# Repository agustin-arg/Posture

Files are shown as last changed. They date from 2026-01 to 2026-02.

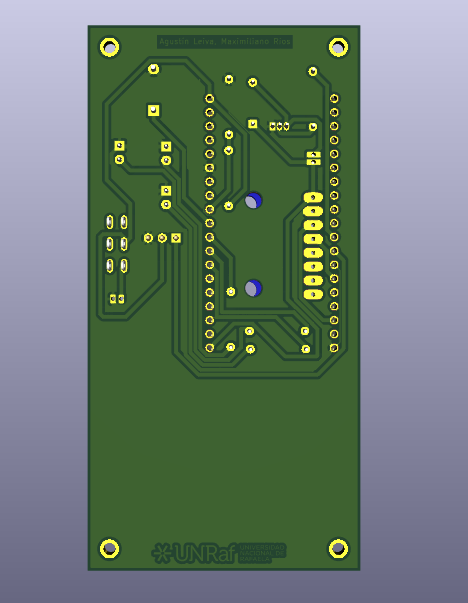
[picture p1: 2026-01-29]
pcb/design/renders/Vista inferior de la PCB - distribución de pistas y puntos de soldadura..png

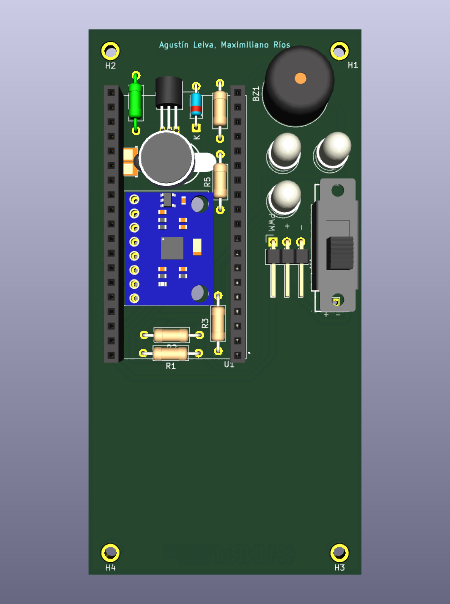
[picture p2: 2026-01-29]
pcb/design/renders/Disposición de componentes en la placa base (sin módulo de control).png

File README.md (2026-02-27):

# **Posture**

Un dispositivo *wearable* que detecta malas posturas en tiempo real y ofrece retroalimentación háptica (vibración), acción mecánica (servomotor), visual (LEDs) y auditiva (buzzer). Incluye conectividad **Bluetooth Low Energy (BLE)** para configuración y monitoreo remoto.

## **Características**

* **Feedback Multimodal:**  
  * **LED Rojo:** Mala postura.  
  * **LED Verde:** Postura correcta.  
  * **Buzzer:** Alerta sonora.  
  * **Vibrador:** Alerta táctil.  
  * **Servomotor:** Acción mecánica correctiva (opcional).  
* **Conectividad BLE:** Permite ver el estado, calibrar y configurar umbrales desde la App móvil.  

## **🛠️ Hardware Requerido y Conexiones**

| Componente | Pin ESP32 (GPIO) | Descripción |
| :---- | :---- | :---- |
| **MPU6050 SDA** | GPIO 21 | Datos I2C |
| **MPU6050 SCL** | GPIO 22 | Reloj I2C |
| **LED Rojo** | GPIO 25 | Indicador de mala postura |
| **LED Verde** | GPIO 33 | Indicador de postura correcta |
| **LED Azul** | GPIO 32 | Estado Bluetooth / Calibración |
| **Buzzer** | GPIO 26 | Alarma sonora (PWM) |
| **Vibrador** | GPIO 18 | Motor de vibración |
| **Servomotor** | GPIO 19 | Servo para corrección física |

## **📂 Estructura del Proyecto**

El código está organizado en 6 archivos para facilitar el mantenimiento:

1. main.py: **Punto de entrada**. Orquesta la inicialización y el bucle principal.  
2. config.py: **Configuración**. Almacena pines, constantes y UUIDs de Bluetooth.  
3. mpu6050.py: **Driver**. Manejo de bajo nivel del sensor I2C.  
4. actuators.py: **Hardware**. Controla LEDs, buzzer, motor y servo.
5. ble\_service.py: **Comunicaciones**. Gestiona la publicidad BLE, conexión y características GATT.  
6. posture\_logic.py: **Matemáticas**. Contiene la física pura y el filtro complementario para calcular el ángulo.

## **🚀 Instalación y Uso**

1. **Flashear MicroPython:** Asegúrate de que tu ESP32 tenga instalado el firmware de MicroPython más reciente.  
2. **Subir Archivos:** Sube los 6 archivos .py a la raíz del dispositivo (usando Thonny IDE, ampy o rshell).  
3. **Encendido:** Reinicia el ESP32.  
4. **Calibración (Importante):**  
   * Colócate el dispositivo en la espalda en una **postura correcta**.  
   * Envía el comando de calibración vía BLE o espera la secuencia inicial.  
   * El **LED Azul** parpadeará 3 veces (tomando datos).  
   * El **LED Verde** se encenderá por 1 segundo confirmando el éxito.  
5. **Funcionamiento:** Si te inclinas más allá del umbral (por defecto 20°), el dispositivo te alertará.

## **📱 Especificaciones Bluetooth (BLE)**

Para desarrollar o conectar Posture App (link), utiliza los siguientes UUIDs definidos en config.py:

**Service UUID:** 0000180f-0000-1000-8000-00805f9b34fb

| Característica | UUID (Prefijo 0000...) | Permisos | Función |
| :---- | :---- | :---- | :---- |
| **Status** | ...2a19... | Read, Notify | Notifica 1 si hay mala postura, 0 si es buena. |
| **Threshold** | ...2a1b... | Read, Write | Lee o establece el ángulo límite (ej. 20°). |
| **Calibrate** | ...2a1c... | Write | Escribe cualquier valor para iniciar calibración. |
| **System** | ...2a22... | Read, Write | 1 \= Encendido, 0 \= Apagado (Standby). |
| **Buzzer** | ...2a1e... | Read, Write | 1 \= Enable, 0 \= Disable. |
| **Vibrator** | ...2a1f... | Read, Write | 1 \= Enable, 0 \= Disable. |
| **LEDs** | ...2a20... | Read, Write | 1 \= Enable, 0 \= Disable. |

## **⚙️ App de Android**

Se incluye una app de Android para poder enciende o apaga actuadores vía Bluetooth y muestra imágenes a modo de monitoreo

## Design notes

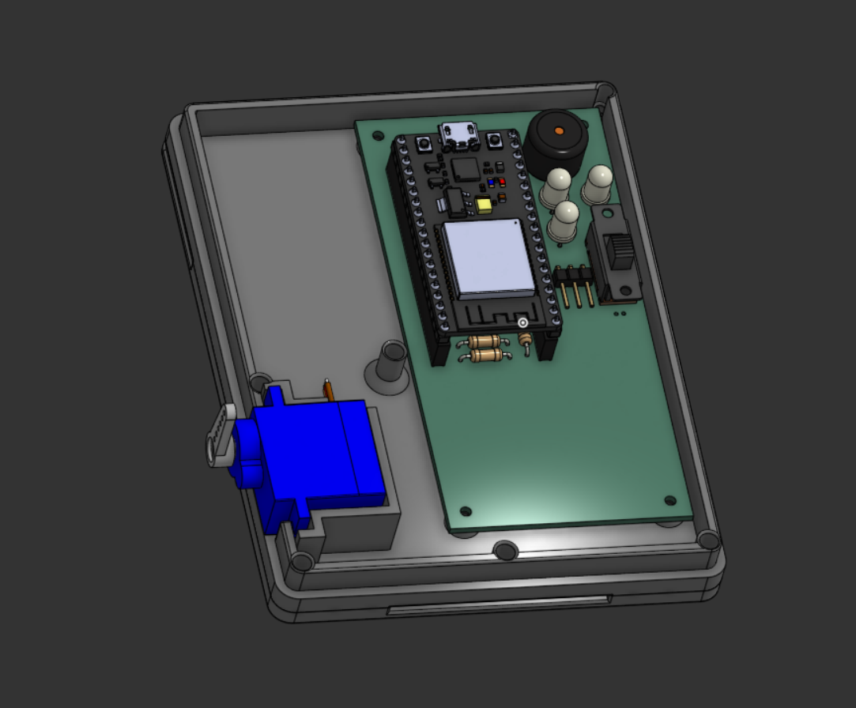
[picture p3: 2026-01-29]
enclosure/renders/Carcasa - Caja inferior y hardware.png

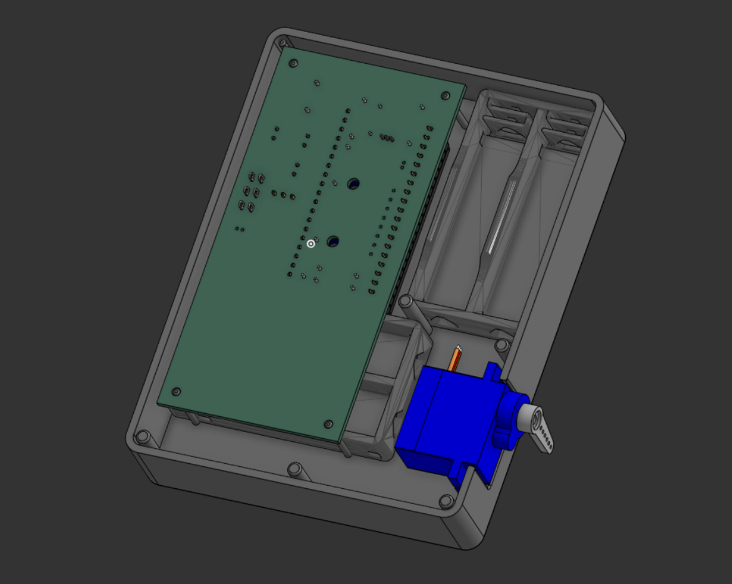
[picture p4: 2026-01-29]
enclosure/renders/Carcasa - Caja superior y hardware.png

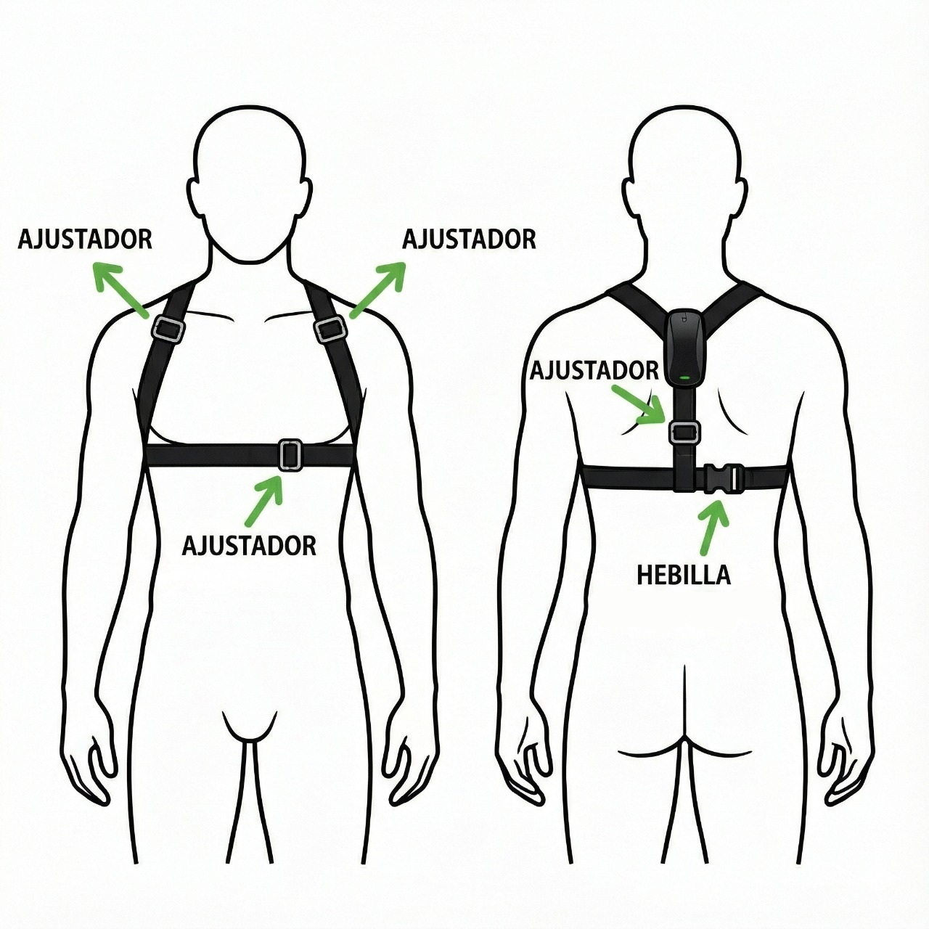
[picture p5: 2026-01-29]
assets/Propuesta de Modo de uso y ubicación del prototipo.jpeg

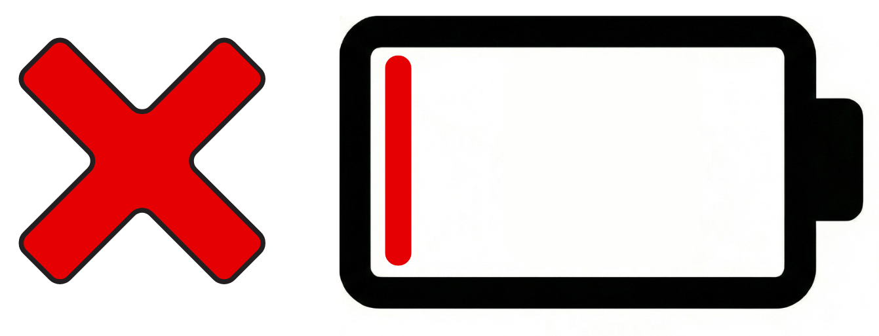
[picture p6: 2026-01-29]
assets/battery_low.png

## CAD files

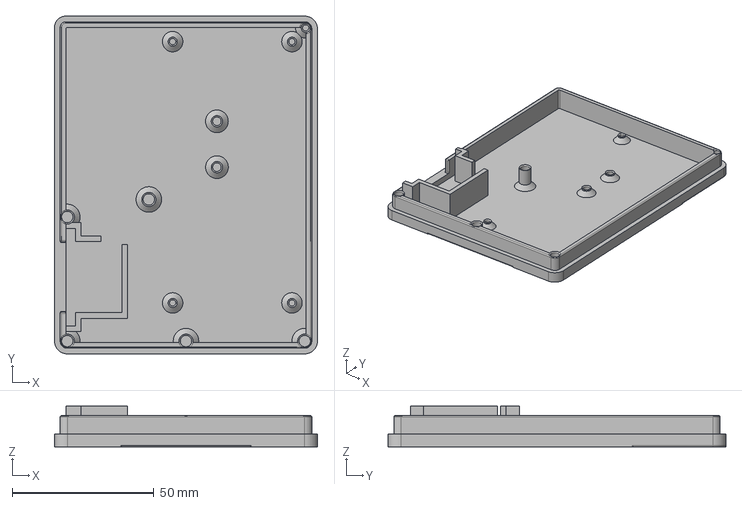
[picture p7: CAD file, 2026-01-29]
enclosure/Caja inferior-A.step
92.6 x 119.0 x 14.3 mm

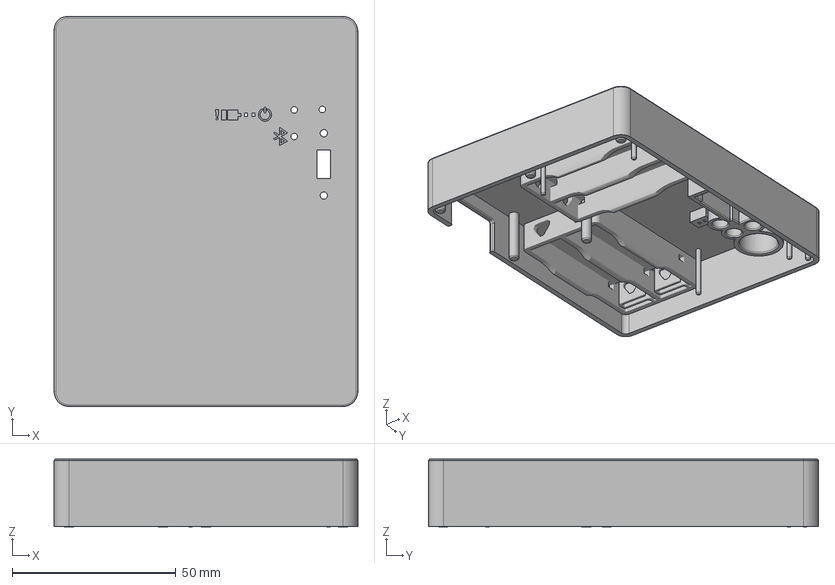
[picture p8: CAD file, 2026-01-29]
enclosure/Caja superior.step
92.6 x 119.0 x 20.7 mm

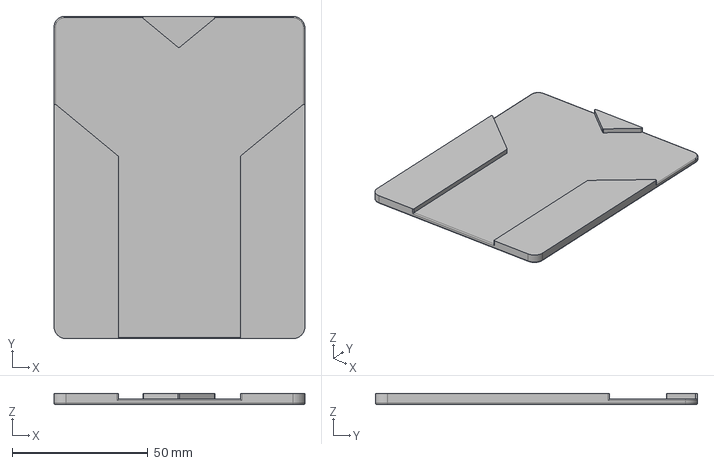
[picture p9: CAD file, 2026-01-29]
enclosure/Caja inferior-B.step
92.6 x 119.0 x 4.00 mm

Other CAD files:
enclosure/Caja inferior-A.stl
enclosure/Caja inferior-B.stl
enclosure/Caja superior.stl

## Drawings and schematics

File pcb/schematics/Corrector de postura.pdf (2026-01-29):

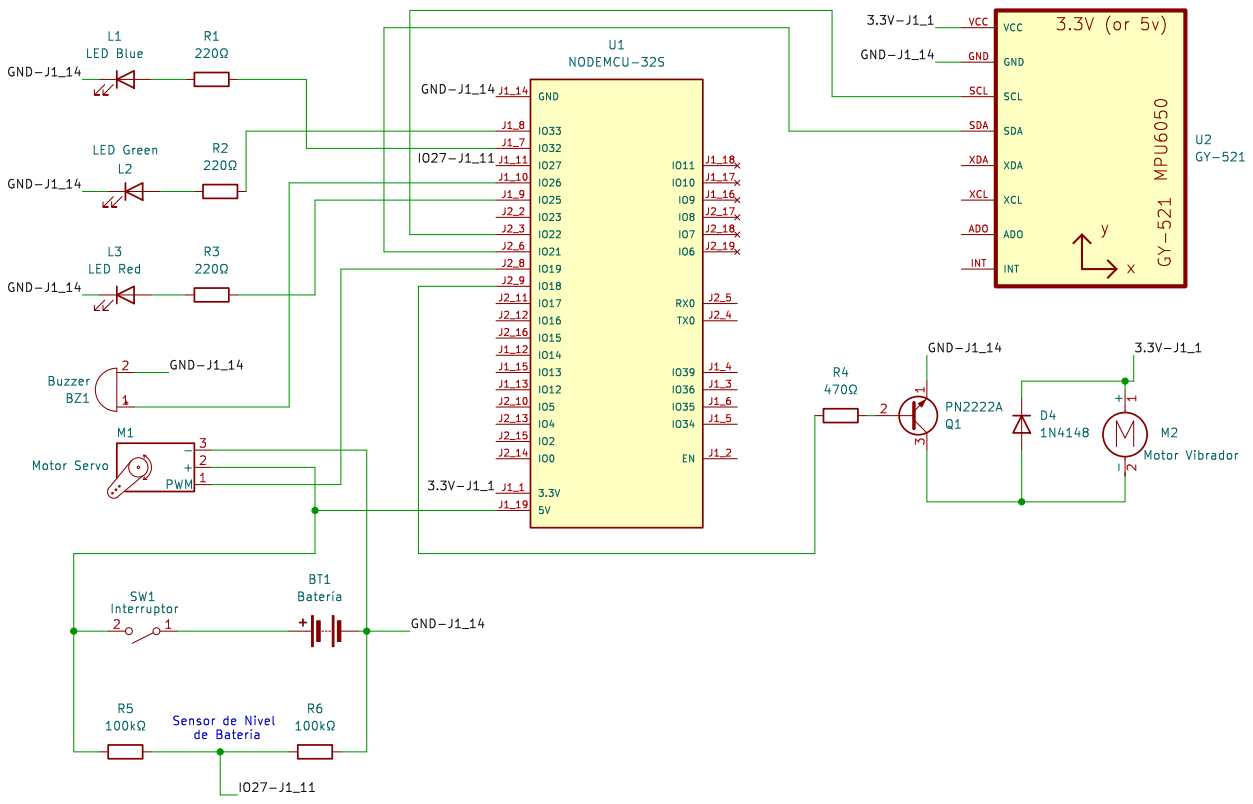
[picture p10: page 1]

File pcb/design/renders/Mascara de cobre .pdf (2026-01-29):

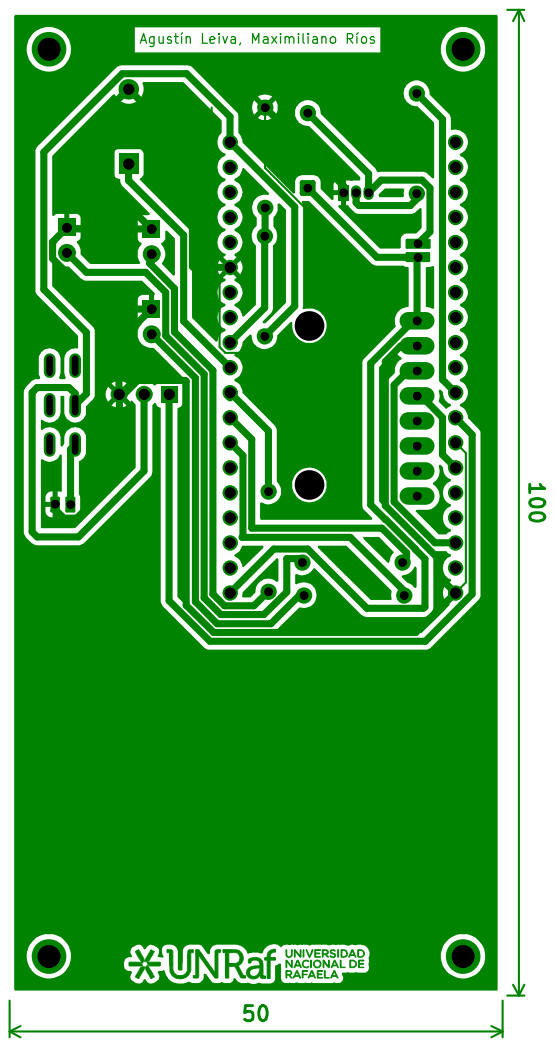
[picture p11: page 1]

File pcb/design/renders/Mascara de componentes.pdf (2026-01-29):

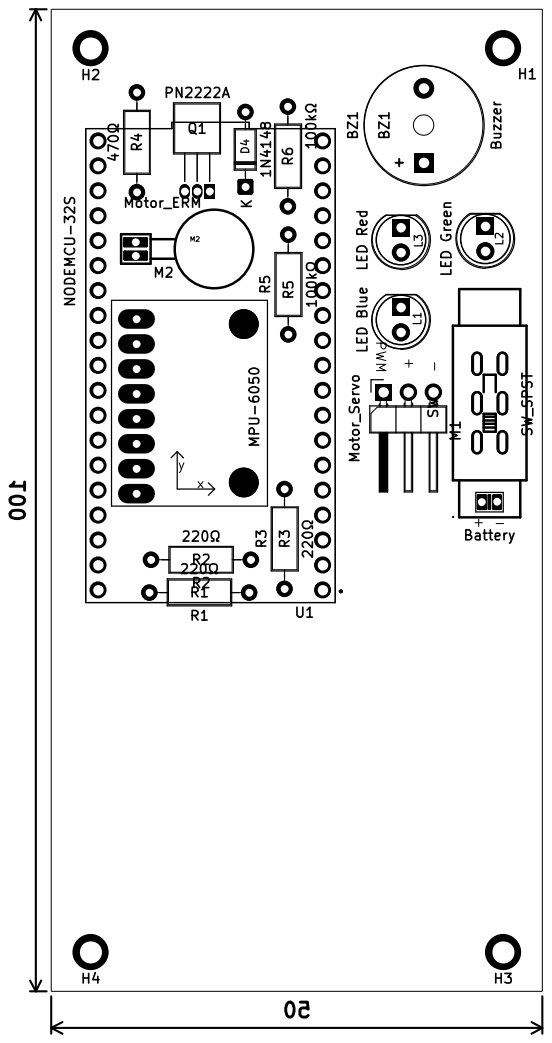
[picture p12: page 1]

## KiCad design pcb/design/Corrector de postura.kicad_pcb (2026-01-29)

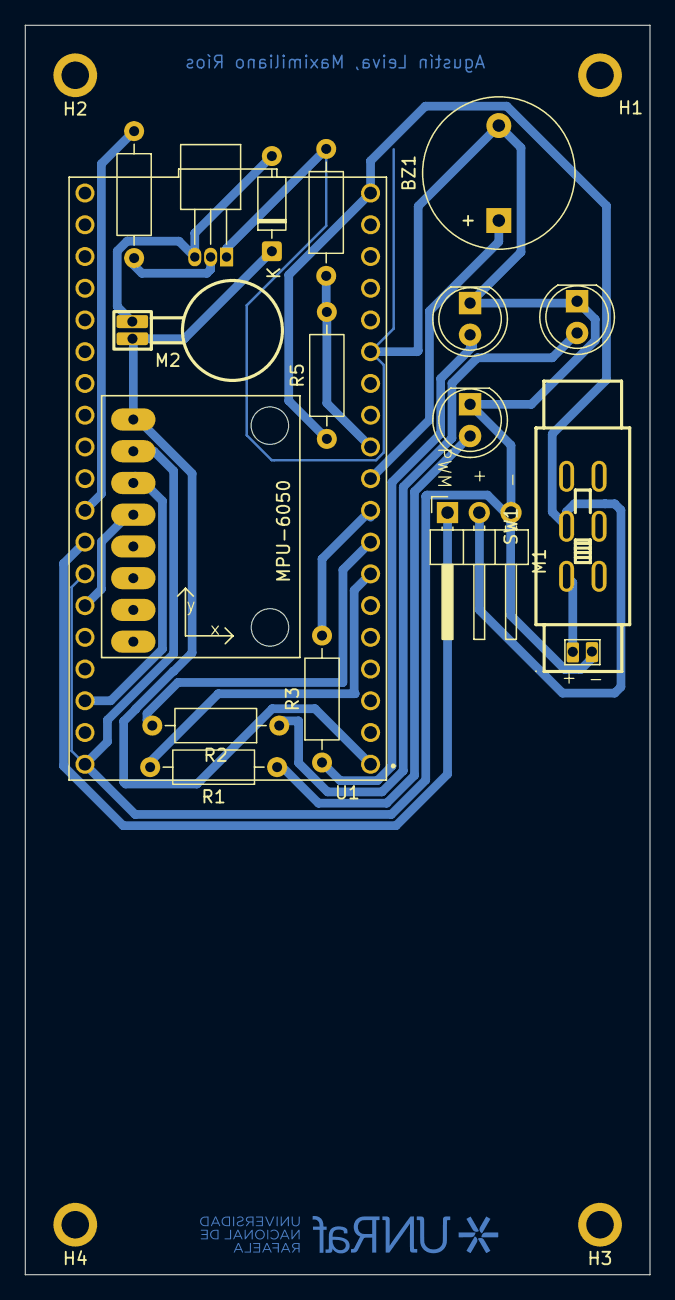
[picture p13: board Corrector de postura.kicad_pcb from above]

Board: 2 copper layers, 50.0 x 100.0 mm, 22 parts (0 on the bottom side), 18 nets.

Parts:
BT1: Battery; SolderJumper-2_P1.3mm_Open_Pad1.0x1.5mm
BZ1: Buzzer; Buzzer_12x9.5RM7.6
D4: 1N4148; D_DO-35_SOD27_P7.62mm_Horizontal
H1: H1; MountingHole_2.2mm_M2_ISO7380_Pad
H2, H3, H4: MountingHole_2.2mm_M2_ISO7380_Pad
L1: LED Blue; LED_D5.0mm_Clear
L2: LED Green; LED_D5.0mm_Clear
L3: LED Red; LED_D5.0mm_Clear
M1: Motor_Servo; PinHeader_1x03_P2.54mm_Horizontal
M2: Motor_ERM; motor
Q1: PN2222A; TO-92_Inline_Horizontal1
R1, R2, R3: 220Ω; R_Axial_DIN0207_L6.3mm_D2.5mm_P10.16mm_Horizontal
R4: 470Ω; R_Axial_DIN0207_L6.3mm_D2.5mm_P10.16mm_Horizontal
R5, R6: 100kΩ; R_Axial_DIN0207_L6.3mm_D2.5mm_P10.16mm_Horizontal
SW1: SW_SPST; SW-TH_SS-22F25-G050
U1: NODEMCU-32S; MODULE_NODEMCU-32S
U2: GY-521

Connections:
/3.3V-J1_1: D4.1 (K), M2.1 (+), U1.J1_1 (3.3V), U2.VCC
/IO27-J1_11: R5.2, R6.1, U1.J1_11 (IO27)
GND: BT1.2 (-), BZ1.2 (-), L1.1 (K), L2.1 (K), L3.1 (K), M1.3 (-), Q1.1 (E), R6.2, U1.J1_14 (GND), U1.J2_1 (GND), U1.J2_7 (GND), U2.GND
unnamed: BT1.1 (+), SW1.1 (A)
unnamed: BZ1.1 (+), U1.J1_10 (IO26)
unnamed: D4.2 (A), M2.2 (-), Q1.3 (C)
unnamed: L1.2 (A), R1.1
unnamed: L2.2 (A), R2.1
unnamed: L3.2 (A), R3.1
unnamed: M1.2 (+), R5.1, SW1.2 (B), U1.J1_19 (5V)
unnamed: M1.1 (PWM), U1.J2_8 (IO19)
unnamed: Q1.2 (B), R4.2
unnamed: R4.1, U1.J2_9 (IO18)
unnamed: U1.J2_6 (IO21), U2.SDA
unnamed: U1.J2_3 (IO22), U2.SCL
unnamed: R3.2, U1.J1_9 (IO25)
unnamed: R1.2, U1.J1_7 (IO32)
unnamed: R2.2, U1.J1_8 (IO33)

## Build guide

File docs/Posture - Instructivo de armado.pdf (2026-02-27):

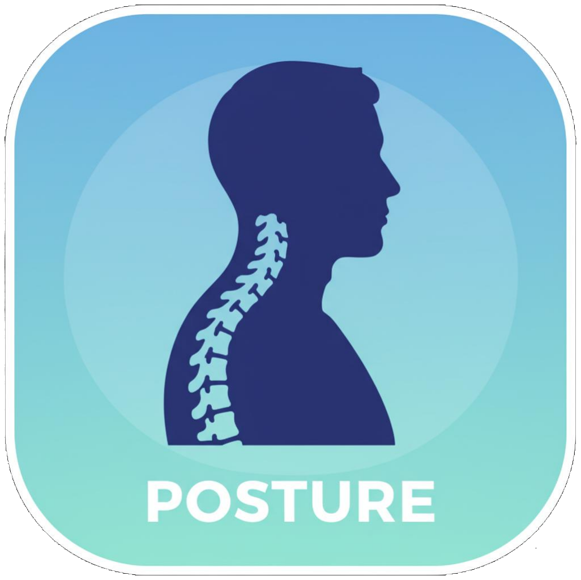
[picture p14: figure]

# Instructivo de armado

## Sistema de Alertas para la Corrección Postural

## 1. Protoboard (“Half-Board” de 400 nodos)

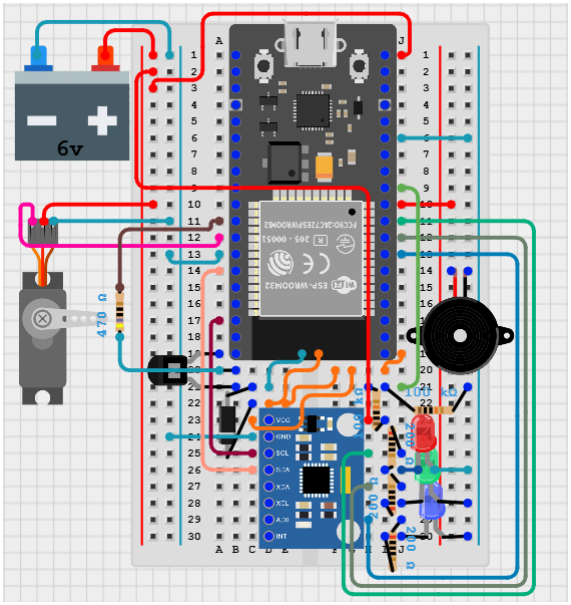
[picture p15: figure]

1. Monte la placa de desarrollo NodeMCU-32S con el puerto USB orientado hacia el extremo superior de la placa de pruebas. Inserte los pines en los nodos de las columnas B e I, desde la fila 1 a la fila 19.
2. Conecte un pin del motor vibrador en el nodo 21D y otro en 22D, al no tener polaridad es indistinto si conecta uno u otro.
3. Inserte los pines de la unidad de medición inercial MPU-6050 en la columna D desde la fila 23 hasta la fila 30.
4. Conecte el transistor 2N2222 con el colector en el nodo 21A, la base en el nodo 20B y el emisor en nodo 19A. Coloque un diodo con el ánodo en el nodo en la fila 21 y el cátodo en la fila 22.
5. Conecte el buzzer piezoeléctrico a los rieles positivo y negativo respectivamente.

6. LEDs: Conecte los ánodos de los pines en cualquiera de los nodos del riel negativo. derecho mientras sea posible y conecte el cátodo del LED rojo en el nodo 26J, el LED verde en el nodo 28J y el cátodo del LED azul en el nodo 30J.
7. Resistencias:
1. Medidor de Voltaje: Coloque una resistencia de 100 kiloOhmios en los nodos 21H y 23I, luego añada otra conectando el nodo 21I con el riel negativo derecho
2. Para los LEDs: Necesitará 3 resistencias de 200 kiloOhmios: coloque una en los nodos 30I y 29J, otra en los nodos 28I y 27J y luego una resistencia en 26I y 25J
3. Para el transistor: Conecte una resistencia de 470 Ohmios al nodo 20A con el pin de GND de la placa de desarrollo (nodo 11A).
8. Cableado:
1. Conecte un pin en el nodo 20I al pin 3.3V de la placa de desarrollo (nodo 19J).
2. Conecte un cable en el nodo 22E a un nodo de la mitad derecha de la fila 20.
3. Conecte el VCC del sensor inercial a un nodo de la mitad derecha de la fila 20.
4. Conecte el GND del sensor inercial al riel negativo izquierdo
5. Conecte el SCL del sensor inercial al pin correspondiente de la placa de desarrollo (GPIO22 – nodo 17A).
6. Conecte el pin SDA del sensor inercial al pin correspondiente de la placa de desarrollo (GPIO 21 – nodo 14A).
7. Conecte un cable desde el nodo 29H a un pin GPIO de la placa de desarrollo (En la imagen: nodo 13J).
8. Conecte un cable desde el nodo 27H a un pin GPIO de la placa de desarrollo (En la imagen: nodo 12J).
9. Conecte un cable desde el nodo 25H a un pin GPIO de la placa de desarrollo (En la imagen: nodo 11J).
10. Conecte un cable desde el nodo 10J al riel positivo derecho de la placa de pruebas.
11. Conecte un cable desde el nodo 21J al nodo 9J.
12. Conecte un cable desde el nodo 6J al riel negativo derecho.
13. Conecte el GND izquierdo (nodo 13A) al riel negativo izquierdo.
14. Conecte el pin de PWM del servomotor a un pin GPIO de la placa de desarrollo (En la imagen: nodo 12A)
15. Conecte el pin VCC del servomotor al riel positivo izquierdo de la placa de pruebas.
16. Conecte el pin GND del servomotor al riel negativo izquierdo de la placa de pruebas.
17. Conecte el borne positivo de la fuente de alimentación al riel positivo izquierdo.
18. Conecte el borne negativo de la fuente de alimentación al riel negativo izquierdo de la placa de pruebas.
19. Conecte el nodo 23H al riel positivo izquierdo de la placa de pruebas.
20. Conecte el nodo correspondiente al pin 5V de la placa de desarrollo al riel positivo izquierdo de la placa de pruebas.

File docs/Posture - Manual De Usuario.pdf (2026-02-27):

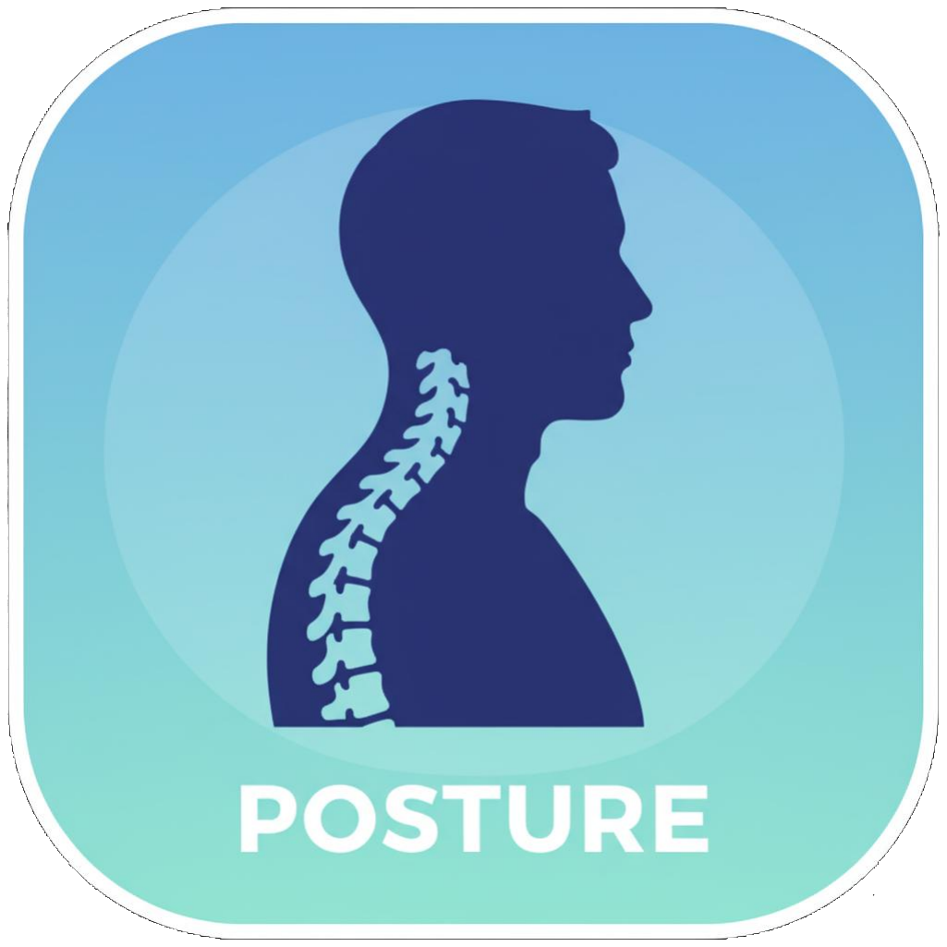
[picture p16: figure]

# MANUAL DE USUARIO

## Sistema de Alertas para la Corrección Postural

### 1. Introducción

Posture es un sistema compuesto por un dispositivo electrónico y una app dedicada, pensado para la alerta y seguimiento de la postura corporal del usuario en los casos donde esta sea incorrecta.

Este dispositivo está dirigido a aquellas personas que tienen problemas de postura corporal principalmente hipercifosis en la zona dorsal preferiblemente en posición erguida, aunque su uso puede extenderse a otras situaciones cotidianas como sentarse en una silla o acostarse en una cama.

Este manual describe instrucciones de uso y solución a problemas comunes para la instalación, configuración y activación del sistema.

### 2. Antes de empezar

Versiones de Sistema Operativo recomendados:
- Android 2.1 “Eclair” o posteriores
- IOS 9.0 o posteriores para iPhone, iPad o iPod Touch
- macOS 11 o superior en computadoras con Apple M1 Silicon

Bluetooth 4.0 o superior

4 baterías AA de 1.5 V

Vista general del dispositivo

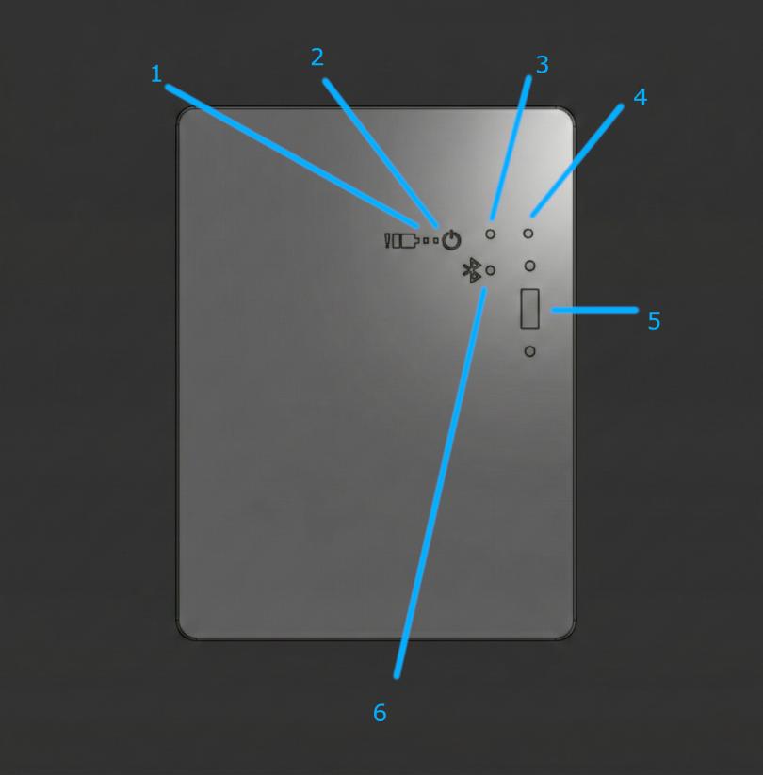
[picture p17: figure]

1. LED de batería baja
2. LED de encendido
3. LED de estado de “buena postura”
4. LED de estado de “mala postura”
5. Interruptor deslizable de encendido
6. LED de conexión Bluetooth

Interfaz de usuario

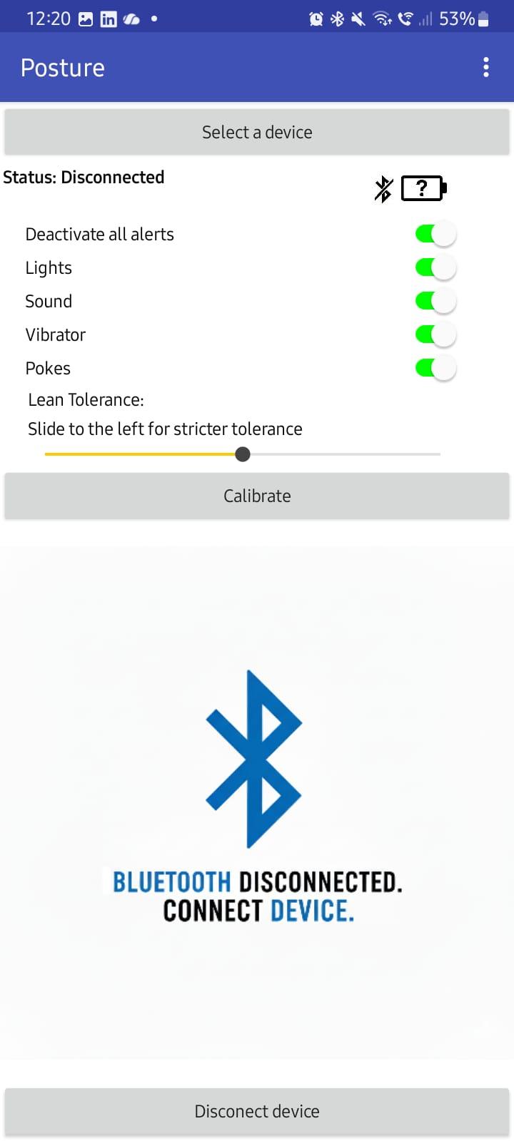
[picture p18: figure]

De arriba hacia abajo:

1. Título y menú de la aplicación
2. Botón de emparejamiento Bluetooth
3. Estado de la batería e ícono de estado de la batería
4. Interruptores de personalización de alertas
1. Desactivar todas las alertas
2. Luces
3. Sonido

4. Vibración
5. Toques
5. Botón de Calibración
6. Apoyo visual mediante imágenes para los distintos estados del dispositivo
7. Botón de desconexión de Bluetooth
3. Primeros pasos y modo de uso.
1. Descargue la aplicación escaneando el QR debajo:

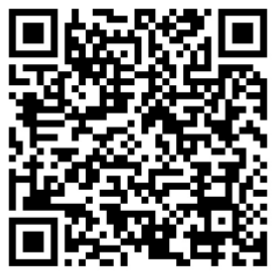
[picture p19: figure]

https://drive.google.com/file/d/1PgvyIUCKR38C9H2EwZNRgdO78sglIsU0/

Nota: Debido a que la aplicación no se encuentra en tiendas oficiales, su smartphone puede mostrar una advertencia de “Contenido no seguro” al descargar la app. Asegúrese de tenerla activada la opción “Instalar Aplicaciones de Origen Desconocido” en los Ajustes de su teléfono.

2. Coloque las baterías en la fuente de alimentación.
3. Encienda el dispositivo. Una luz azul parpadeará indicando que el dispositivo está en modo emparejamiento esperando una conexión Bluetooth.
4. Introduzca los brazos a través del arnés y sitúe el sensor en la parte superior de la espalda (zona interescapular).
5. Utilice las cinchas de ajuste para regular la tensión, asegurándose de que el dispositivo quede firme. Verifique que ambos tirantes tengan la misma longitud para garantizar una distribución uniforme de la presión sobre los hombros.
6. Ingrese a la aplicación. Pulse el botón “Select a device” y una lista de dispositivos aparecerá en pantalla. Seleccione “Posture”. La luz azul del dispositivo cesará su intermitencia indicando una conexión Bluetooth exitosa.
7. Colóquese en una postura con la espalda erguida y pulse el botón “Calibrate”. La luz azul emitirá un breve parpadeo mientras el sensor registra su eje de inclinación.
8. Una vez finalizado, el dispositivo validará su posición de referencia y una luz verde se activará indicando estado de “Buena postura” mientras que una luz roja indicará estado de “Mala postura”. Adicionalmente, se activarán alertas sonoras y hápticas, así como también la aplicación también mostrará imágenes según el estado.

Puede activar o desactivar alertas pulsando en los diferentes interruptores en la aplicación.

### 4. Recomendaciones de uso

- Tiempo de uso: Se recomienda su uso en bloques de 1 a 2 horas. Un uso continuado por más de 11 horas requerirá el reemplazo de las baterías.
- Recalibración por cambio de actividad: El eje de inclinación de referencia puede variar si pasa de estar sentado en una silla de oficina a estar sentado en un sofá o de pie. Se recomienda realizar una nueva calibración cada vez que cambie su entorno o posición de trabajo principal.
- Ajuste de sensibilidad: Si nota que el dispositivo vibra o cambia a luz roja ante movimientos mínimos y naturales, ajuste el umbral de tolerancia para evitar avisos excesivos que agoten la batería prematuramente.

### 5. Resolución de Problemas comunes

Problema | Causa probable | Solución sugerida
El sensor no enciende. | Pilas mal instaladas o agotadas. | Verifique que los polos (+/-) coincidan con el diagrama del compartimento. Sustituya ambas pilas por unas nuevas de 1.5V.
La App no detecta el dispositivo. | Bluetooth desactivado o falta de permisos. | Active el Bluetooth en su smartphone. Asegúrese de haber concedido permisos de "Ubicación" y "Dispositivos cercanos" a la App.
El LED azul parpadea indefinidamente. | Error de vinculación. | Reinicie la aplicación. Si el problema persiste, apague y encienda el sensor para reiniciar el modo de emparejamiento.
Alertas constantes de "Mala postura". | Calibración incorrecta o sensor desplazado. | Verifique que el sensor esté centrado entre los omóplatos. Adopte la posición erguida y realice una nueva calibración desde la App.
No hay alertas visuales en la App. | Desconexión del enlace inalámbrico. | Verifique que el dispositivo esté dentro del rango de alcance (5 metros). Compruebe que el indicador LED del sensor no esté apagado.
El dispositivo se apaga durante el uso. | Contacto de pilas flojo o batería crítica. | Asegúrese de que la tapa del compartimento de las pilas esté bien cerrada. Si el nivel de batería es inferior

Problema | Causa probable | Solución sugerida
| | al 5%, el sistema puede apagarse automáticamente.

Notas técnicas adicionales para el usuario:

- Interferencias: Evite utilizar el dispositivo cerca de routers Wi-Fi potentes o microondas en funcionamiento, ya que pueden interferir con la señal Bluetooth y provocar desconexiones momentáneas.
- Recuperación de conexión automática: Si se aleja de su smartphone y pierde la conexión, el dispositivo intentará reconectarse automáticamente al volver al rango de alcance. Si no lo hace en 30 segundos, pulse el botón de "Select a device" en la interfaz de la App.
- Temperatura de funcionamiento: Si el dispositivo ha estado expuesto a temperaturas extremas (por ejemplo, dentro de un vehículo al sol), espere a que recupere la temperatura ambiente antes de encenderlo, ya que el calor excesivo afecta temporalmente la sensibilidad del acelerómetro.

### 6. Mantenimiento y Cuidado

Para asegurar la durabilidad del hardware y la higiene de los textiles, siga estas instrucciones de conservación:

### 1. Cuidado del sensor

- Limpieza superficial: Utilice un paño de microfibra seco para retirar el polvo. Si es necesario, humedezca el paño mínimamente con agua o alcohol isopropílico. Nunca aplique líquidos directamente sobre el sensor.
- Protección contra impactos: El acelerómetro interno es un componente de precisión. Evite caídas o golpes fuertes, ya que podrían descalibrar el sensor de inclinación permanentemente.
- Prevención de corrosión: Dado que el dispositivo utiliza pilas AA, si no planea usarlo por más de 7 días, extraiga las pilas. Esto evita que posibles fugas de ácido dañen los contactos metálicos y la placa base.

### 2. Limpieza del arnés

- Desmontaje obligatorio: Antes de cualquier proceso de limpieza, extraiga el sensor de su alojamiento en el arnés.
- Lavado: Lave las cinchas a mano con agua fría y un detergente suave. No utilice suavizantes, ya que pueden degradar las fibras elásticas del arnés.
- Secado: No utilice secadora. Extienda el arnés en una superficie plana y deje secar al aire libre. La exposición directa y prolongada al sol puede restar elasticidad a los tirantes.

### 3. Almacenamiento

- Evite almacenar el dispositivo en ambientes con humedad excesiva (como baños), ya que el vapor de agua puede penetrar en la carcasa del sensor y causar fallos por condensación.

### 7. Especificaciones técnicas

Categoría | Detalle Técnico
Alimentación | 4 Pilas AA de 1.5V (Alcalinas recomendadas).
Autonomía | Hasta 11 horas de uso continuo (según calidad de las pilas).
Sensor principal | Unidad de Medición Inercial MPU-6050.
Rango de inclinación | 0° a 90° (Detección de eje de cabaceo o pitch).
Conectividad | Bluetooth Low Energy (BLE) 4.2.
Alcance inalámbrico | Hasta 10 metros sin obstáculos.
Material del arnés | Poliéster elástico y Nylon (libre de látex).
Compatibilidad App | iOS 9.0+ / Android 2.1+ (requiere Bluetooth activo).
Indicadores visuales | Sistema LED de 3 estados (Azul, Verde, Rojo). Apoyo Visual en la aplicación móvil
Alertas físicas | Motor de vibración háptica integrado. Buzzer piezoeléctrico. Servomotor analógico de giro limitado

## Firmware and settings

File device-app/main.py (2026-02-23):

import utime
from machine import I2C, Pin
import config
from mpu6050 import MPU6050
from actuators import PostureActuators
from ble_service import PostureBLE
from posture_logic import PostureProcessor
from battery_monitor import BatteryMonitor


class PostureApp:
    def __init__(self):
        # 1. Inicializar Hardware I2C y Sensor
        try:
            i2c = I2C(0, sda=Pin(config.PIN_SDA), scl=Pin(config.PIN_SCL))
            self.mpu = MPU6050(i2c)
        except Exception as e:
            print(f"Error I2C: {e}")
            self.mpu = None

        # 2. Inicializar Actuadores
        self.actuators = PostureActuators()

        # 3. Inicializar BLE
        self.ble = PostureBLE()

        # 4. Lógica de Procesamiento
        self.processor = PostureProcessor(alpha=0.98)

        # 5. Monitor de Batería
        self.battery = BatteryMonitor()
        self.last_battery_check = 0
        self.battery_check_interval = config.BAT_CHECK_INTERVAL_MS

        # 6. Estado de la Aplicación
        self.calibrated_angle = 0.0
        self.is_calibrated = False
        self.is_bad_posture = False

    def calibrate(self):
        print("Calibrando...")
        self.actuators.feedback_calibration()

        if self.mpu:
            accel = self.mpu.get_accel_data()
            gyro = self.mpu.get_gyro_data()

            self.processor.reset()
            current_angle = self.processor.calculate_pitch(accel, gyro)

            self.calibrated_angle = current_angle
            self.processor.reset(initial_angle=self.calibrated_angle)

            self.is_calibrated = True
            self.actuators.confirm_calibration()
            print(f"Calibrado a: {self.calibrated_angle:.2f}")
        else:
            print("Error: No hay sensor para calibrar")

        self.ble.calibrate_request = False

    def run(self):
        print(
            f"Sistema iniciado. Chequeo de batería cada {self.battery_check_interval/1000}s"
        )
        last_notified_state = None

        # Notifica la batería una vez
        volts_inicial = self.battery.read_voltage()
        battery_level = self.battery.get_battery_level(volts_inicial)
        self.ble.notify_battery(battery_level)
        if battery_level == 0:
            self.actuators.set_battery_led(True)
        else:
            self.actuators.set_battery_led(False)

        while True:
            now = utime.ticks_ms()

            # --- GESTIÓN DE BATERÍA ---
            if (
                utime.ticks_diff(now, self.last_battery_check)
                > self.battery_check_interval
            ):
                # 1. Revisar hardware y obtener voltaje
                volts = self.battery.check_and_handle_low_battery(self.actuators)

                # 2. Clasificar nivel de batería
                battery_level = self.battery.get_battery_level(volts)

                # 3. Notificar al servicio BLE
                self.ble.notify_battery(battery_level)

                # 4. Controlar LED según nivel de batería
                if battery_level == 0:
                    self.actuators.set_battery_led(True)
                else:
                    self.actuators.set_battery_led(False)

                self.last_battery_check = now

            # 1. Chequear petición de calibración
            if self.ble.calibrate_request:
                self.calibrate()
                utime.sleep_ms(50)
                continue

            # 2. Manejo de estado: Sistema Apagado
            if not self.ble.system_enabled:
                self.actuators.stop_all(keep_ble_led=True)
                if self.ble.conn_handle is None:
                    self.actuators.blink_ble_led()
                else:
                    self.actuators.set_ble_led(True)
                    utime.sleep_ms(100)
                continue

            # 3. Manejo de estado: No Calibrado
            if not self.is_calibrated:
                if self.ble.conn_handle is None:
                    self.actuators.blink_ble_led()
                else:
                    self.actuators.set_ble_led(True)
                    utime.sleep_ms(100)
                continue

            # --- OPERACIÓN NORMAL ---
            if self.mpu:
                accel = self.mpu.get_accel_data()
                gyro = self.mpu.get_gyro_data()
                current_angle = self.processor.calculate_pitch(accel, gyro)

                deviation = abs(current_angle - self.calibrated_angle)
                self.is_bad_posture = deviation > self.ble.threshold_angle

                self.actuators.update(self.is_bad_posture, settings=self.ble)

                if self.ble.conn_handle:
                    self.actuators.set_ble_led(True)

                if self.is_bad_posture != last_notified_state:
                    if self.ble.notify_status(self.is_bad_posture):
                        last_notified_state = self.is_bad_posture

            utime.sleep_ms(100)


if __name__ == "__main__":
    app = PostureApp()
    app.run()

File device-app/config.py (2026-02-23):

import ubluetooth

# --- Configuración de Pines ---
PIN_SDA = 21
PIN_SCL = 22

# Pines de Feedback Visual (Postura y BLE)
PIN_LED_RED = 25  # Mala Postura
PIN_LED_GREEN = 33  # Buena Postura
PIN_LED_BLUE = 32  # Estado Bluetooth

# Pin Exclusivo Batería (LED Integrado)
PIN_LED_BAT_LOW = 2  # Solo se enciende al hibernar

PIN_BUZZER = 26
PIN_VIBRATOR = 18
PIN_SERVO = 19
PIN_BAT = 27  # Entrada ADC Batería

# --- Constantes del Servo ---
SERVO_FREQ = 50
SERVO_ALERT_ANGLE = 90
SERVO_IDLE_ANGLE = 0
SERVO_DEBOUNCE_MS = 300    # Tiempo mínimo de mala postura para confirmar
SERVO_HOLD_MS = 300         # Tiempo en cada posición (alerta / retorno)
SERVO_INTERVAL_MS = 5000    # Pausa entre ciclos de movimiento

# --- Constantes del Buzzer ---
BUZZER_FREQ = 2000          # Frecuencia del tono (Hz) — agudo y audible
BUZZER_BEEP_MS = 120        # Duración de cada "pi"
BUZZER_GAP_MS = 100         # Silencio entre los dos "pi"
BUZZER_INTERVAL_MS = 3660   # Silencio después del "pi-pi" (ciclo total ~4s)

# --- Constantes del Vibrador ---
VIBRATOR_DURATION_MS = 400  # Duración del pulso de vibración
VIBRATOR_INTERVAL_MS = 3600 # Pausa entre pulsos (ciclo total ~4s)

# --- Gestión de Energía ---
BAT_DIVIDER_FACTOR = 2.0
BAT_MIN_VOLTAGE = 4.7  # Voltaje mínimo para hibernar. Recomendado: 4.7V
BAT_CHECK_INTERVAL_MS = 300000  # 5 minutos

# --- Constantes de Batería (Voltaje en V) ---
BATTERY_VOLTAGE_MAX = 5.30
BATTERY_VOLTAGE_MID = 5.00  # Sí baja de este valor ya es LOW
# El vontage cuando esta conectado por usb es LOW

# --- UUIDs de Bluetooth BLE ---
POSTURE_SERVICE_UUID = ubluetooth.UUID("0000180f-0000-1000-8000-00805f9b34fb")
POSTURE_STATUS_CHAR_UUID = ubluetooth.UUID("00002a19-0000-1000-8000-00805f9b34fb")
THRESHOLD_ANGLE_CHAR_UUID = ubluetooth.UUID("00002a1b-0000-1000-8000-00805f9b34fb")
CALIBRATE_CHAR_UUID = ubluetooth.UUID("00002a1c-0000-1000-8000-00805f9b34fb")
BUZZER_CONTROL_CHAR_UUID = ubluetooth.UUID("00002a1e-0000-1000-8000-00805f9b34fb")
VIBRATOR_CONTROL_CHAR_UUID = ubluetooth.UUID("00002a1f-0000-1000-8000-00805f9b34fb")
LEDS_CONTROL_CHAR_UUID = ubluetooth.UUID("00002a20-0000-1000-8000-00805f9b34fb")
NOTIFY_CONTROL_CHAR_UUID = ubluetooth.UUID("00002a21-0000-1000-8000-00805f9b34fb")
SYSTEM_CONTROL_CHAR_UUID = ubluetooth.UUID("00002a22-0000-1000-8000-00805f9b34fb")
BATTERY_NOTIFY_CHAR_UUID = ubluetooth.UUID("00002a23-0000-1000-8000-00805f9b34fb")
SERVO_CONTROL_CHAR_UUID  = ubluetooth.UUID("00002a24-0000-1000-8000-00805f9b34fb")

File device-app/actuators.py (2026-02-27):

from machine import Pin, PWM
import utime
import config


class PostureActuators:
    def __init__(self):
        # LEDs de Postura
        self.led_red = Pin(config.PIN_LED_RED, Pin.OUT)
        self.led_green = Pin(config.PIN_LED_GREEN, Pin.OUT)
        self.led_blue = Pin(config.PIN_LED_BLUE, Pin.OUT)

        # LED de Batería Baja
        self.led_battery_low = Pin(config.PIN_LED_BAT_LOW, Pin.OUT)
        self.led_battery_low.off()

        # Inicializar Buzzer y Vibrador
        self.buzzer = PWM(Pin(config.PIN_BUZZER), freq=220, duty=0)
        self.vibrator = Pin(config.PIN_VIBRATOR, Pin.OUT, value=0)

        # Inicializar Servo
        try:
            self.servo = PWM(Pin(config.PIN_SERVO), freq=config.SERVO_FREQ, duty=0)
        except Exception:
            self.servo = None

        # Variables de estado interno del Servo
        # _servo_state: 0=IDLE, 1=ALERT, 2=RETURN, 3=COOLDOWN
        self._servo_state = 0
        self._servo_debounce_since = 0
        self._servo_phase_until = 0

        # Variables de estado del Buzzer (patrón "pi-pi")
        self._buzzer_cycle_start = 0

        # Variables de estado del Vibrador (pulso periódico)
        self._vib_active_until = 0
        self._vib_next_trigger = 0

    def set_ble_led(self, state):
        """Controla el LED Azul para estado de conexión"""
        self.led_blue.value(1 if state else 0)

    def blink_ble_led(self):
        """Parpadeo del LED Azul para indicar espera"""
        self.led_blue.on()
        utime.sleep_ms(50)
        self.led_blue.off()
        utime.sleep_ms(950)

    def signal_battery_low(self):
        """
        Señal única en el PIN 2 (LED Integrado) antes de morir.
        Se enciende fijo por 2 segundos.
        """
        self.led_battery_low.on()
        utime.sleep(2)
        self.led_battery_low.off()

    def feedback_calibration(self):
        """Secuencia visual: Parpadeo LED Azul"""
        for _ in range(3):
            self.led_blue.on()
            utime.sleep_ms(100)
            self.led_blue.off()
            utime.sleep_ms(100)

    def confirm_calibration(self):
        """Confirmación visual: LED Verde"""
        self.led_green.on()
        utime.sleep_ms(1000)
        self.led_green.off()

    def stop_all(self, keep_ble_led=True):
        """Apaga actuadores principales (Rojo, Verde, Motores)"""
        self.led_red.off()
        self.led_green.off()
        if not keep_ble_led:
            self.led_blue.off()

        # El LED de batería (Pin 2) no se apaga aquí porque
        # normalmente stop_all se llama antes de hibernar

        try:
            self.buzzer.duty(0)
        except:
            pass
        self._buzzer_cycle_start = 0

        try:
            self.vibrator.value(0)
        except:
            try:
                self.vibrator.off()
            except:
                pass
        self._vib_active_until = 0
        self._vib_next_trigger = 0

        try:
            if self.servo:
                self.servo.duty(0)
        except:
            pass
        self._servo_state = 0
        self._servo_debounce_since = 0
        self._servo_phase_until = 0

    def set_battery_led(self, state):
        """Enciende/apaga LED de batería baja"""
        if state:
            self.led_battery_low.on()
        else:
            self.led_battery_low.off()

    def update(self, is_bad_posture, settings):
        """Actualiza LEDs Rojo/Verde y Motores"""
        # 1. LEDs Postura
        if settings.leds_enabled:
            self.led_red.value(is_bad_posture)
            self.led_green.value(not is_bad_posture)
        else:
            self.led_red.off()
            self.led_green.off()

        # 2. Buzzer (patrón "pi-pi" periódico)
        self._update_buzzer(is_bad_posture, settings.buzzer_enabled)

        # 3. Vibrador (pulso periódico, no constante)
        self._update_vibrator(is_bad_posture, settings.vibrator_enabled)

        # 4. Servo (ciclo periódico cada SERVO_INTERVAL_MS)
        self._update_servo(is_bad_posture, settings.servo_enabled)

    def _angle_to_duty(self, angle):
        min_duty = 25
        max_duty = 75
        if angle is None:
            return 0
        a = max(0, min(90, int(angle)))
        return int(min_duty + (a / 90.0) * (max_duty - min_duty))

    def _update_buzzer(self, is_bad_posture, enabled):
        """
        Patrón "pi-pi": dos beeps cortos (BUZZER_BEEP_MS cada uno,
        separados por BUZZER_GAP_MS) seguidos de silencio BUZZER_INTERVAL_MS.
        Ciclo total ≈ 4 segundos. Se resetea al recuperar buena postura.
        """
        if not enabled or not is_bad_posture:
            self.buzzer.duty(0)
            self._buzzer_cycle_start = 0
            return

        now = utime.ticks_ms()

        # Iniciar ciclo al entrar en mala postura
        if self._buzzer_cycle_start == 0:
            self._buzzer_cycle_start = now

        elapsed = utime.ticks_diff(now, self._buzzer_cycle_start)
        total_cycle = (
            config.BUZZER_BEEP_MS
            + config.BUZZER_GAP_MS
            + config.BUZZER_BEEP_MS
            + config.BUZZER_INTERVAL_MS
        )

        # Reiniciar ciclo al completarse
        if elapsed >= total_cycle:
            self._buzzer_cycle_start = now
            elapsed = 0

        t1 = config.BUZZER_BEEP_MS
        t2 = t1 + config.BUZZER_GAP_MS
        t3 = t2 + config.BUZZER_BEEP_MS

        if elapsed < t1:
            # Primer "pi"
            self.buzzer.freq(config.BUZZER_FREQ)
            self.buzzer.duty(512)
        elif elapsed < t2:
            # Pausa entre "pi-pi"
            self.buzzer.duty(0)
        elif elapsed < t3:
            # Segundo "pi"
            self.buzzer.freq(config.BUZZER_FREQ)
            self.buzzer.duty(512)
        else:
            # Silencio hasta el siguiente ciclo
            self.buzzer.duty(0)

    def _update_vibrator(self, is_bad_posture, enabled):
        """
        Pulso periódico: ON durante VIBRATOR_DURATION_MS,
        luego OFF durante VIBRATOR_INTERVAL_MS. Ciclo total ≈ 4 segundos.
        El motor no está activo continuamente, lo que evita interferencias
        con las lecturas del MPU6050. Se resetea al recuperar buena postura.
        """
        if not enabled or not is_bad_posture:
            self.vibrator.value(0)
            self._vib_next_trigger = 0
            self._vib_active_until = 0
            return

        now = utime.ticks_ms()

        # Primera activación: disparar inmediatamente
        if self._vib_next_trigger == 0:
            self._vib_active_until = utime.ticks_add(now, config.VIBRATOR_DURATION_MS)
            self._vib_next_trigger = utime.ticks_add(
                now, config.VIBRATOR_DURATION_MS + config.VIBRATOR_INTERVAL_MS
            )
            self.vibrator.value(1)
            return
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

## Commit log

2026-01-04 fix: typo en actuators.py
    [actuators.py]
2026-01-29 Added KiCAD project designs and schematics, Onshape project enclosure and other.
    [Caja inferior-A.step, Caja inferior-A.stl, Caja inferior-B.step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]
2026-02-22 fix: - The get_battery_level(voltage) function has been moved. -notify_battery() now directly receives the `battery_level`. -The workflow has been updated: battery_monitor first reads and classifies 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
    [battery_monitor.py, ble_service.py, main.py]
2026-02-22 feat: Add servo control characteristics and update posture logic for gyro axis
2026-02-22 feat: Enhance servo, buzzer, and vibrator control logic for improved posture feedback
    [actuators.py]
2026-02-22 Fix: Update the Posture application for servo control service
